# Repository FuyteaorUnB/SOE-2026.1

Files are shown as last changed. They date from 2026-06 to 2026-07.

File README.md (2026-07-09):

# Sistema de Controle de Acesso Biométrico

### Reconhecimento facial e detecção de vivacidade embarcados, com processamento local e núcleo de tempo real







> Portaria eletrônica residencial que reconhece os moradores, detecta ataques de apresentação (foto/tela) e aciona uma trava solenoide, sem enviar nenhum dado biométrico para a nuvem. Todo o processamento acontece dentro de uma Raspberry Pi 3.

**Autor:** Fernando de Melo Colli — 231026349
**Disciplina:** Sistemas Operacionais Embarcados — FCTE / Universidade de Brasília
**Estágio:** Entrega final (migração completa de Python para C/C++)

---

## Índice

- [Visão geral](#visão-geral)
- [Arquitetura de software](#arquitetura-de-software)
- [Hardware](#hardware)
- [Como o reconhecimento funciona](#como-o-reconhecimento-funciona)
- [Viés de dataset descoberto e corrigido](#viés-de-dataset-descoberto-e-corrigido)
- [Detecção de vivacidade (liveness)](#detecção-de-vivacidade-liveness)
- [A decisão final: três barreiras](#a-decisão-final-três-barreiras)
- [Recursos de tempo real do Linux](#recursos-de-tempo-real-do-linux)
- [Como rodar](#como-rodar)
- [Calibração e resultados](#calibração-e-resultados)
- [Estrutura do repositório](#estrutura-do-repositório)
- [Trabalhos futuros](#trabalhos-futuros)
- [Referências](#referências)

---

## Visão geral

Diferente de soluções comerciais como Ring ou Nest, que dependem de servidores externos, este projeto realiza todo o processamento localmente (*Edge Computing*), mantendo o dado biométrico dentro do dispositivo. O sistema é composto por **dois processos concorrentes** que se comunicam por um *pipe* nomeado (FIFO):

| Processo | Papel |
| --- | --- |
| `visao` | Captura a câmera, reconhece o rosto, verifica *liveness* e emite um veredito (`F` = autorizado, `I` = intruso). |
| `sistema_core` | Recebe o veredito e controla o hardware (trava solenoide e LED RGB) com garantias de tempo real. |

**Principais características:**

- Reconhecimento facial **LBPH implementado do zero** — depende apenas do OpenCV base (sem `opencv_contrib`, que leva horas para compilar na Pi).
- Normalização de iluminação **Tan-Triggs** idêntica no treino e na inferência.
- **Múltiplos usuários autorizados** (um rótulo por pessoa) + **classe negativa** para robustez contra intrusos.
- Classe negativa **balanceada por etnia** — corrige um viés de dataset descoberto nos testes.
- **Anti-spoofing** com 4 métricas de vivacidade (LBP, Laplaciano, Sobel, FFT).
- Núcleo de controle com **tempo real**: `mlockall`, `SCHED_FIFO`, afinidade de CPU e tarefa periódica absoluta.
- IPC estável, **sem perda de bytes**, via descritor de leitura persistente com `poll()`.
- Notificação de intruso (foto) via Telegram.

---

## Arquitetura de software

```mermaid
flowchart LR
    CAM([Webcam USB 320x240]) --> VISAO

    subgraph P1 [Processo: visao]
        VISAO[Reconhecimento facial<br/>+ liveness]
    end

    subgraph P2 [Processo: sistema_core]
        CORE[Núcleo de controle<br/>tempo real]
    end

    VISAO -- "FIFO /tmp/gate_pipe<br/>'F' = autorizado<br/>'I' = intruso" --> CORE
    CORE -- GPIO 17 --> TRAVA([Trava solenoide 12V])
    CORE -- GPIO 22/27/10 --> LED([LED RGB])
```

Toda a matemática compartilhada (Tan-Triggs, LBPH, FFT) vive em um único *header*, **`visao_core.hpp`**, o que garante que treino e inferência processem as imagens de forma **idêntica** — a correção central de um bug do estágio anterior.

| Arquivo | Função |
| --- | --- |
| `core.cpp` | Núcleo de controle do hardware + recursos de tempo real |
| `visao.cpp` | Pipeline de visão (reconhecimento + *liveness*) |
| `visao_core.hpp` | Algoritmos compartilhados (Tan-Triggs, LBPH, FFT) |
| `treinar.cpp` | Treino do classificador (captura multi-ângulo e por *datasets*) |
| `extrair_rostos.cpp` | Extração de rostos de terceiros para a classe negativa |
| `baixar_rostos.sh` | Baixa rostos sintéticos (StyleGAN) para a classe negativa |
| `baixar_diversidade.py` | Baixa rostos de etnias sub-representadas (correção do viés) |
| `atualizar_negativos.sh` | Pipeline: baixar → extrair → retreinar, com resumo |
| `Makefile` | Compilação |
| `haarcascade_frontalface_default.xml` | Detector de rostos (Viola-Jones) |

---

## Hardware

### Lista de materiais (BOM)

| Componente | Qtd. |
| --- | ---- |
| Raspberry Pi 3 Model B | 1 |
| Trava Solenoide 12 V | 1 |
| Fonte de Alimentação 12 V | 1 |
| Transistor TIP31C (NPN, potência) | 1 |
| Transistor BC548 (NPN, driver) | 1 |
| Diodo Retificador 1N4007 (*flyback*) | 1 |
| Resistor 330 Ω | 4 |
| Resistor 10 kΩ | 1 |
| LED RGB de cátodo comum | 1 |
| Capacitor Eletrolítico 470 µF / 20 V | 1 |
| Webcam USB | 1 |

### Diagrama de blocos

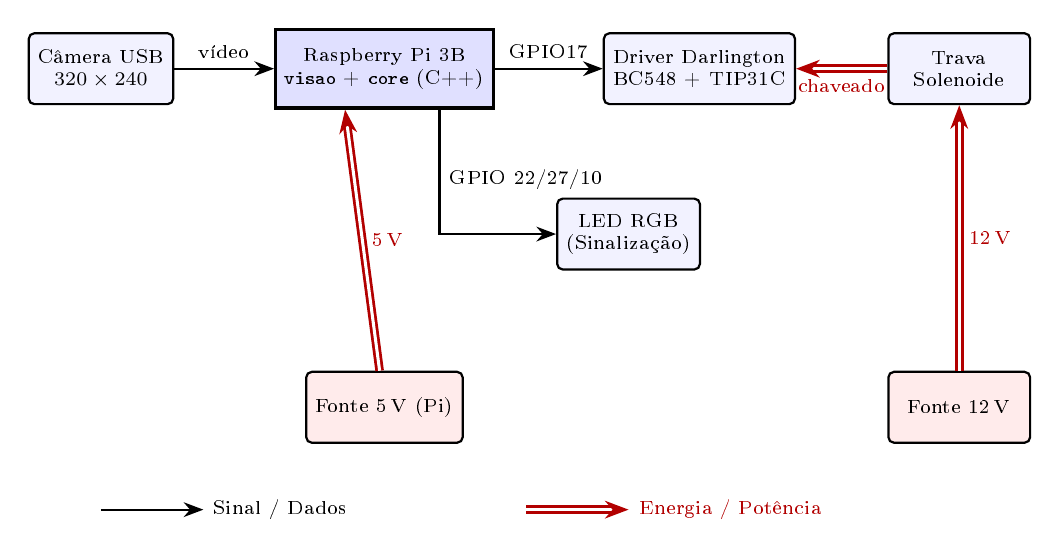
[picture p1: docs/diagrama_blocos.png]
Diagrama de blocos


### Estágio de potência e esquemático

O acionamento da solenoide usa um **par Darlington (BC548 + TIP31C)** como chave de baixo lado:

- **GPIO 17** controla a base do BC548 através de um resistor de **330 Ω**; um resistor de *pull-down* de **10 kΩ** garante o estado desligado sem sinal.
- O coletor do BC548 liga ao **5 V**; o emissor vai à base do TIP31C, cujo coletor chaveia a solenoide.
- A solenoide é alimentada pelo barramento de **12 V**, com um **diodo *flyback* 1N4007** em antiparalelo com a bobina (cátodo no +12 V) para suprimir o pico de tensão reversa no desligamento.
- Um capacitor de **470 µF/20 V** filtra o barramento de 5 V.
- O **LED RGB** (cátodo comum) é acionado pelas **GPIOs 22 / 27 / 10**, cada perna com um resistor de 330 Ω.

> **Terra comum:** as fontes de 5 V (Pi) e 12 V devem compartilhar o **mesmo terra**. A ausência dessa continuidade causa a anomalia do "LED fantasma".

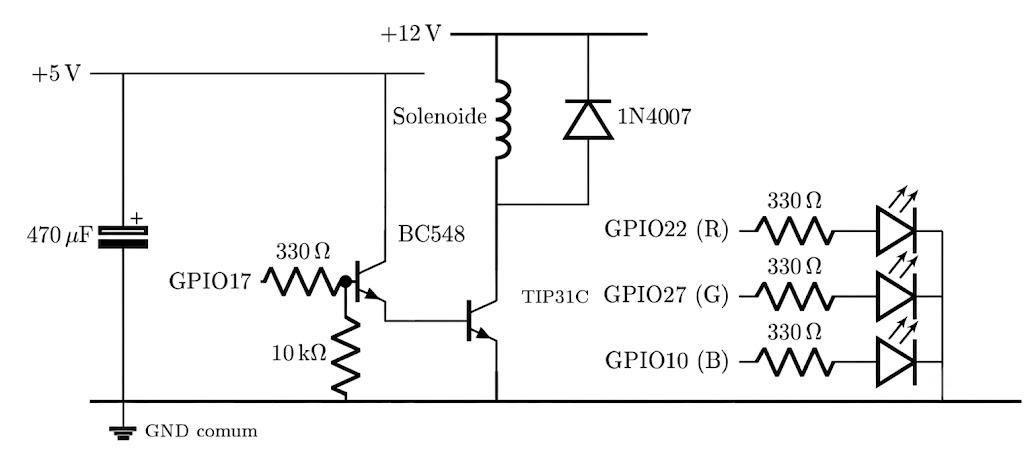
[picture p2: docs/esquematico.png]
Esquemático


---

## Como o reconhecimento funciona

O classificador é um **LBPH (Local Binary Patterns Histograms) por vizinho mais próximo**, implementado do zero. É importante entender que **ele não constrói um retrato médio** — não existe "borrão" de rostos sobrepostos:

1. **Detecção:** o rosto é localizado na cena pelo **Haar Cascade** (Viola-Jones). *(etapa separada e anterior ao reconhecimento)*
2. **Pré-processamento canônico** (`preprocessarFace`): recorte → redimensionamento para **120×120** → normalização **Tan-Triggs** de iluminação. **Aplicado de forma idêntica no treino e na inferência.**
3. **Descrição:** cada rosto vira um **histograma espacial de LBP** — grade **8×8**, 256 *bins* por célula = vetor de **16.384 floats**.
4. **Classificação (1-NN):** o rosto novo é comparado, por **distância χ²**, contra **todas** as amostras guardadas, e recebe o rótulo daquela **mais próxima**.

### Usuários e rótulos

O treino usa **uma pasta por identidade** (lista `USUARIOS_AUTORIZADOS` no `treinar.cpp`):

| Rótulo | Pasta | Conteúdo |
| --- | --- | --- |
| **1**  | `dataset_fernando/` | Usuário autorizado 1 (multi-ângulo) |
| **3**  | `dataset_amigo/` | Usuário autorizado 2 (multi-ângulo) |
| **2**  | `dataset_outros/` | Terceiros — a **classe negativa** |

A captura guiada (`./treinar --capturar`) conduz a pessoa por **7 fases de pose** (frontal, rotações, queixo levantado, perto/longe, contraluz), 30 amostras por fase = **210 amostras por usuário**.

### Por que existe uma "classe negativa"

Cada imagem é guardada como uma **amostra individual** — a classe negativa é uma **galeria de estranhos**, não uma média. O acesso só é liberado quando o rótulo previsto é de um usuário autorizado (≠ 2).

- **Sem a classe negativa:** o `predict()` só teria rótulos autorizados e **sempre** devolveria "usuário". A única defesa seria um limiar de distância — uma fronteira **absoluta** (uma esfera de raio `CONF_MAX` em torno das amostras do usuário). Um rosto parecido (um amigo) pode cair dentro dessa esfera e ser aceito, e apertar o raio passa a rejeitar o próprio usuário.
- **Com a classe negativa:** a decisão passa a ser **relativa** — um rosto só é aceito se estiver **mais próximo de uma amostra de usuário do que de qualquer estranho da galeria**. Mesmo que a distância do intruso até o usuário seja baixa, se houver um estranho ainda mais próximo, o vizinho mais próximo é o rótulo 2 → **acesso negado**, independentemente do limiar.

> Em uma frase: troca-se uma fronteira esférica frágil ("está perto de mim?") por uma fronteira de Voronoi discriminativa ("parece mais comigo ou com algum estranho?").

---

## Viés de dataset descoberto e corrigido

Durante os testes com voluntários, o sistema **barrava estranhos brancos mas aceitava um voluntário asiático** como usuário autorizado. A causa: a classe negativa vinha de terceiros locais e da StyleGAN do *thispersondoesnotexist* (treinada no dataset FFHQ), **ambos enviesados para rostos brancos**. Sem nenhum negativo asiático próximo no espaço de características, o rosto do voluntário caía no vizinho autorizado mais parecido — um falso positivo **estrutural**.

**Correção:** o script `baixar_diversidade.py` baixa rostos de nove grupos étnicos sub-representados; `extrair_rostos` os recorta e `treinar` reconstrói o modelo. Após o balanceamento, o falso positivo desapareceu.

> É um caso concreto de **viés de dataset em *open-set recognition***: a robustez da fronteira discriminativa depende diretamente da cobertura da galeria negativa.

---

## Detecção de vivacidade (liveness)

Para cada quadro, quatro métricas atacam ataques de apresentação (foto impressa ou tela de celular):

| Métrica | O que mede | Limiar |
| --- | --- | --- |
| **LBP** (variância de padrões uniformes) | Textura de pele real vs. superfície plana | `> 3.7`  |
| **Laplaciano** (variância) | Nitidez / micro-detalhe | `> 28` |
| **Sobel** (desvio do gradiente) | Riqueza de bordas | `> 12` |
| **FFT** (razão de energia alta/baixa freq.) | Detalhe de alta frequência ausente em telas | `> 0.65` |

Um quadro é considerado **REAL** se o *score* ≥ 3 **e** LBP **e** FFT passarem.

---

## A decisão final: três barreiras

Os vereditos por quadro entram em **janelas deslizantes de 10 quadros** (com *reset* após 12 s sem rosto). A porta só abre quando **as três barreiras** são satisfeitas ao mesmo tempo:

1. **Identidade consistente:** ≥ **9/10** quadros da **mesma** identidade autorizada (rótulo ≠ 2, `Conf < 38`);
2. **Vivacidade:** ≥ **6/10** quadros REAIS, com **pico de Laplaciano > 80** na janela (ao menos um quadro nítido);
3. **Distância:** abaixo de `CONF_MAX` em cada quadro contado.

Satisfeitas as três → `F` no FIFO (trava abre por 4 s). Se menos de 4 quadros forem reais ou autorizados → `I` + **foto da cena no Telegram** (intervalo mínimo de 20 s entre notificações). Um intruso não consegue satisfazer as três barreiras simultaneamente.

---

## Recursos de tempo real do Linux

O `sistema_core` emprega recursos de tempo real para garantir **latência determinística** no acionamento da trava:

| Recurso | Chamada de sistema | Efeito |
| --- | --- | --- |
| **Memória travada** | `mlockall(MCL_CURRENT \| MCL_FUTURE)` | Impede que páginas vão para o *swap* em um momento crítico |
| **Escalonamento RT** | `SCHED_FIFO` (prioridade 50) | A thread crítica executa assim que o byte chega, sem ser preemptada |
| **Afinidade de CPU** | `pthread_setaffinity_np` | Monitor na CPU 3, LED na CPU 2 — evita migração e *jitter* de cache |
| **Tarefa periódica absoluta** | `clock_nanosleep(CLOCK_MONOTONIC, TIMER_ABSTIME)` | LED em período exato de 100 ms, sem *drift* acumulado |

O núcleo usa duas threads (`std::thread`): uma que escuta o FIFO com `poll()` (sem *busy-wait*) e outra que atualiza o LED. O estado compartilhado é protegido por `std::mutex`, e `SIGINT`/`SIGTERM` garantem encerramento limpo.

> Os recursos de tempo real exigem privilégios — rode o `sistema_core` com `sudo`.

---

## Como rodar

> **Ambiente-alvo:** Raspberry Pi 3 Model B (ou qualquer Linux com OpenCV base e V4L2).

### 1. Dependências

```bash
sudo apt update
sudo apt install -y g++ make libopencv-dev pkg-config
# 'pinctrl' já vem no Raspberry Pi OS recente (usado para as GPIOs)
```

### 2. Compilar

```bash
make            # gera: sistema_core, visao e treinar
```

Para (re)gerar a ferramenta da classe negativa (não incluída no `make all`):

```bash
g++ -O2 -std=c++17 $(pkg-config --cflags opencv4) \
    extrair_rostos.cpp -o extrair_rostos $(pkg-config --libs opencv4)
```

### 3. Treinar o classificador

**a) Capturar os rostos dos usuários autorizados** (guia interativo de 7 ângulos):

```bash
./treinar --capturar                        # usuário 1 → dataset_fernando/ (rótulo 1)
./treinar --capturar dataset_amigo 3        # usuário 2 → dataset_amigo/  (rótulo 3)
```

**b) Montar a classe negativa** — automática (recomendado):

```bash
./atualizar_negativos.sh 60      # baixa 60 rostos sintéticos, extrai e retreina
python3 baixar_diversidade.py    # rostos de etnias diversas (balanceamento)
./extrair_rostos fotos_diversas/*/*.jpg
```

ou manual, com fotos próprias:

```bash
./extrair_rostos foto1.jpg foto2.jpg ...
```

**c) Treinar a partir das pastas** (gera `modelo_lbph.txt`):

```bash
./treinar
```

### 4. Calibrar (opcional, recomendado)

Roda o pipeline **sem disparar ações**, só imprimindo métricas — útil para ajustar os limiares:

```bash
./visao --calibrar
```

### 5. Executar o sistema

Em **dois terminais** (ou via `systemd` / `&`):

```bash
# Terminal 1 — núcleo de controle (precisa de sudo p/ tempo real e GPIO)
sudo ./sistema_core
```

```bash
# Terminal 2 — pipeline de visão
./visao
```

Para as notificações do Telegram, defina `TELEGRAM_TOKEN` e `TELEGRAM_CHAT_ID` no topo do `visao.cpp` antes de compilar (**não versione o token** — o valor padrão `COLOQUE_SEU_...` mantém as notificações desativadas).

> Os binários carregam `haarcascade_frontalface_default.xml`, `modelo_lbph.txt` e as pastas `dataset_*` **pelo diretório de trabalho atual** — rode-os a partir da pasta onde esses arquivos estão. `make clean` remove os binários.

---

## Calibração e resultados

A calibração foi **iterativa, com pessoas reais** (modo `--calibrar`). Os limiares finais:

| Parâmetro | Valor |
| --- | ----- |
| `CONF_MAX` (distância χ² máxima) | 38 |
| `LBP_MIN` | 3,7 |
| `LAP_MIN` | 28 |
| `GRAD_STD_MIN` | 12 |
| `FFT_RATIO` | 0,65  |
| `LAP_PICO_MIN` (pico na janela)  | 80 |

**Composição final do modelo (`modelo_lbph.txt`): 833 amostras** — 210 do usuário 1, 210 do usuário 2 e 413 negativos balanceados por etnia.

**Resultados:**

- **Identidade:** usuários legítimos aceitos de forma consistente, com `Conf` **34–38 estável** sob variação de iluminação (era **84–98** antes da correção Tan-Triggs).
- **Intruso:** classificado como rótulo 2 em **80–90%** dos quadros → a barreira de identidade (≥ 9/10) impede a abertura.
- **Viés corrigido:** após o balanceamento étnico da classe negativa, o falso positivo estrutural desapareceu.
- **Anti-spoofing:** foto em tela de celular → rótulo 2 ou reprovação nas métricas de textura → alerta + notificação no Telegram.
- **IPC:** estável, **sem perda de bytes**, graças ao descritor de leitura persistente com `poll()`.
- **Tempo real:** `mlockall`, `SCHED_FIFO` e afinidade de CPU bem-sucedidos nos quatro núcleos da Pi 3; LED em período exato de 100 ms.
- **CPU:** consumo baixo, pela ausência de *busy-wait* e pelo *sleep* de 150 ms entre quadros.

---

## Estrutura do repositório

```
.
├── README.md
├── Makefile
├── .gitignore
├── core.cpp                              # Núcleo de controle + tempo real
├── visao.cpp                             # Pipeline de visão (liveness + reconhecimento)
├── visao_core.hpp                        # Algoritmos compartilhados (Tan-Triggs, LBPH, FFT)
├── treinar.cpp                           # Treino do classificador
├── extrair_rostos.cpp                    # Extração de rostos p/ a classe negativa
├── baixar_rostos.sh                      # Rostos sintéticos (negativos genéricos)
├── baixar_diversidade.py                 # Rostos de etnias diversas (balanceamento)
├── atualizar_negativos.sh                # Pipeline: baixar → extrair → retreinar
├── haarcascade_frontalface_default.xml   # Detector de rostos
└── docs/
    ├── Trabalho_SOE.pdf                  # Relatório final do projeto
    ├── diagrama_blocos.png
    ├── esquematico.png
    ├── fluxograma.png
    └── SOE-v1.fzz                        # Projeto Fritzing do circuito
```

> **Observação:** o modelo `modelo_lbph.txt` e as pastas `dataset_*/` e `fotos_*/` são **dados biométricos**, gerados localmente e **não versionados** (ver `.gitignore`). As credenciais do bot do Telegram também não são versionadas.

---

## Trabalhos futuros

- Substituir o LBPH por **embeddings faciais de rede neural** (mais tolerantes a pose e iluminação).
- Migrar o acionamento de GPIO de `system("pinctrl")` para **libgpiod** (menos *overhead* e mais determinismo na thread de tempo real).

---

## Referências

- P. Viola, M. Jones — *Rapid Object Detection using a Boosted Cascade of Simple Features*, CVPR 2001.
- T. Ojala, M. Pietikäinen, T. Mäenpää — *Multiresolution Gray-Scale and Rotation Invariant Texture Classification with LBP*, IEEE PAMI 2002.
- T. Ahonen, A. Hadid, M. Pietikäinen — *Face Description with Local Binary Patterns*, IEEE PAMI 2006.
- X. Tan, B. Triggs — *Enhanced Local Texture Feature Sets for Face Recognition under Difficult Lighting Conditions*, IEEE TIP 2010.
- T. Karras, S. Laine, T. Aila — *A Style-Based Generator Architecture for Generative Adversarial Networks*, CVPR 2019.
- W. R. Stevens, S. A. Rago — *Advanced Programming in the UNIX Environment*, 3rd ed., 2013.
- M. Kerrisk — *The Linux Programming Interface*, No Starch Press, 2010.

---

*Desenvolvido para a disciplina de Sistemas Operacionais Embarcados — FCTE / UnB · 2026*

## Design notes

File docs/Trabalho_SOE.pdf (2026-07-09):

# Sistema de Controle de Acesso Biométrico com Processamento Local e Defesa contra Ataques de Apresentação

Fernando de Melo Colli - 231026349 Faculdade de Ciências e Tecnologias em Engenharia (FCTE) Universidade de Brasília

Resumo—Este trabalho apresenta a entrega final de um sistema de controle de acesso residencial biométrico, embarcado integralmente em uma Raspberry Pi 3 Model B com processamento local (Edge Computing) — o dado biométrico não sai do dispositivo. O software, todo em C/C++, consolida um sistema concorrente de dois processos que se comunicam por um pipe nomeado (FIFO): uma pipeline de visão (visao) e um núcleo de controle de tempo real (sistema_core), que emprega travamento de memória (mlockall), escalonamento SCHED_FIFO, afinidade de CPU e tarefa periódica com clock_nanosleep absoluto, garantindo latência determinística no acionamento da trava. O reconhecimento facial (LBPH implementado do zero, sem dependência do opencv_contrib) usa normalização de iluminação Tan-Triggs idêntica no treino e na inferência, suporta múltiplos usuários autorizados e emprega uma classe negativa — uma galeria de rostos de terceiros — que transforma o limiar absoluto de distância em uma fronteira discriminativa contra intrusos. Durante os testes, identificou-se e corrigiu-se um viés étnico nessa classe negativa, um caso concreto de viés de dataset em reconhecimento de conjunto aberto (open-set). A decisão de abertura exige três barreiras simultâneas em uma janela deslizante de 10 quadros: identidade consistente, vivacidade (liveness, 4 métricas anti-spoofing) e distância abaixo do limiar. Os resultados demonstram um protótipo estável: identidade consistente sob variação de iluminação, rejeição de intrusos e de ataques de apresentação, e comunicação entre processos sem perda de bytes.

I. INTRODUÇÃO

A segurança residencial demanda autonomia e privacidade. Diferente de soluções comerciais como Ring [1] ou Nest [2], que dependem de servidores externos, este projeto realiza todo o processamento localmente (Edge Computing), mantendo o dado biométrico dentro do dispositivo. O sistema implementa uma portaria eletrônica com reconhecimento facial, detecção de vivacidade (liveness) e acionamento de uma trava solenoide. Esta entrega final consolida o refinamento do protótipo ao longo dos pontos de controle, com cinco objetivos: (i) migrar todo o código de Python para C/C++; (ii) adicionar recursos de tempo real do Linux ao núcleo de controle [9], [10]; (iii) corrigir os falsos negativos de identidade observados no PC3 sob variação de iluminação; (iv) tornar o classificador robusto contra intrusos por meio de uma classe negativa, com suporte a múltiplos usuários autorizados; e (v) identificar e corrigir o viés étnico descoberto nessa classe negativa durante os testes com pessoas reais. As seções seguintes descrevem o hardware

(II-A), a arquitetura de software em C++ (II-B), o processo de calibração e os resultados (III).

II. DESENVOLVIMENTO DO PROJETO

A. Descrição de Hardware

O sistema utiliza uma Raspberry Pi 3 Model B como núcleo. A lógica de controle e a sinalização (driver e LED RGB) são alimentadas pelo barramento de 5 V da própria Pi, enquanto a trava solenoide é acionada por uma fonte de 12 V. As duas fontes compartilham um barramento de terra comum — ponto cuja garantia corrige a anomalia elétrica (LED fantasma) observada no PC3. A Tabela I lista os materiais.

Tabela I
LISTA DE MATERIAIS (BOM) – IMPLEMENTAÇÃO REAL (PC4)
Componente | Quantidade
Raspberry Pi 3 Model B | 1
Trava Solenoide 12 V | 1
Fonte de Alimentação 12 V | 1
Transistor TIP31C (NPN, potência) | 1
Transistor BC548 (NPN, driver) | 1
Diodo Retificador 1N4007 (flyback) | 1
Resistor 330 Ω | 4
Resistor 10 kΩ | 1
LED RGB de cátodo comum | 1
Capacitor Eletrolítico 470 µF / 20 V | 1
Webcam USB | 1
1) Diagrama de Blocos: O diagrama de blocos da Fig. 1 mostra os componentes de hardware. Os fluxos de sinal/dados aparecem como setas finas e os de energia/potência como setas grossas duplas. A lógica é alimentada pelo barramento de 5 V da Raspberry Pi e a solenoide por uma fonte de 12 V, ambas com terra comum.


Figura 1. Diagrama de blocos do sistema: componentes de hardware, com distinção entre fluxos de sinal (setas finas) e de energia (setas grossas).

2) Estágio de Potência e Esquemático: O acionamento da solenoide usa um par Darlington (BC548 + TIP31C) como chave de baixo lado. A GPIO 17 controla a base do BC548 através de um resistor de 330 Ω; um resistor de pull-down de 10 kΩ garante o estado desligado na ausência de sinal. O coletor do BC548 liga-se ao 5 V e seu emissor à base do TIP31C, cujo coletor chaveia a solenoide e cujo emissor vai ao terra. A solenoide é alimentada pelo barramento de 12 V (terminal positivo no +12 V), e um diodo flyback 1N4007 fica em antiparalelo com a bobina (cátodo, lado da listra cinza, no +12 V) para suprimir o pico de tensão reversa no desligamento. Um capacitor eletrolítico de 470 µF/20 V filtra o barramento de 5 V. O LED RGB de cátodo comum é acionado pelas GPIOs 22/27/10, cada perna com um resistor de 330 Ω. O esquemático completo é apresentado na Fig. 2.

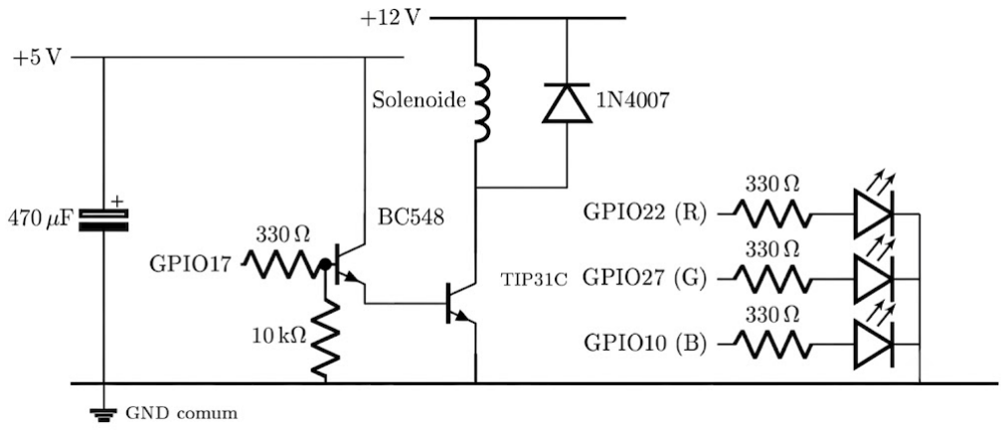
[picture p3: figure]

Figura 2. Esquema elétrico: par Darlington BC548 + TIP31C acionando a solenoide a partir do barramento de 12 V, com diodo de roda-livre 1N4007, capacitor de filtro de 470 µF e LED RGB de sinalização.

B. Descrição de Software

Todos os scripts Python dos estágios anteriores foram reescritos em C++. O sistema permanece como dois processos independentes sincronizados por um pipe nomeado (FIFO) em /tmp/gate_pipe: o processo visao envia o veredito (’F’ = autorizado, ’I’ = intruso) e o sistema_core aciona o hardware. A Tabela II resume a migração.

Tabela II
MIGRAÇÃO DE PYTHON (PC3) PARA C++ (ENTREGA FINAL).
PC3 (Python) | Final (C++) | Função
vision.py | visao.cpp | Pipeline de visão
treinar_e_ver.py | treinar.cpp | Treino do classificador
treinar_increm.py | (no treinar.cpp) | Absorvido
main.cpp | core.cpp | Núcleo + tempo real
— | visao_core.hpp | Algoritmos compartilhados
— | extrair_rostos.cpp | Extração de rostos
1) Núcleo de Controle e Recursos de Tempo Real: O core.cpp controla exclusivamente o hardware por meio
de duas threads (std::thread): threadMonitorPipe,
que escuta o FIFO com poll() (sem busy-wait), e threadControleLED, que atualiza a sinalização. O estado compartilhado é protegido por std::mutex (mtx para o estado e hwMtx para serializar o acesso às GPIOs), e os sinais SIGINT/SIGTERM garantem encerramento limpo. Sobre essa base, empregam-se quatro recursos de tempo real do Linux:
- [RT1] mlockall(MCL_CURRENT | MCL_FUTURE)
— trava toda a memória do processo na RAM, impedindo que páginas sejam enviadas ao swap em um momento crítico (Listagem 1).
- [RT2] SCHED_FIFO — a thread crítica recebe escalonamento de tempo real com prioridade fixa (50), executando imediatamente quando o byte chega, sem ser preemptada por processos comuns.
- [RT3] Afinidade de CPU — cada thread é fixada em um núcleo (monitor na CPU 3, LED na CPU 2), evitando migração entre núcleos e o jitter associado à invalidação de cache (Listagem 2).
- [RT4] Tarefa periódica absoluta — a thread do LED
usa clock_nanosleep com CLOCK_MONOTONIC e
TIMER_ABSTIME: o próximo instante é sempre “anterior + 100 ms”, sem o drift acumulado do sleep_for comum (Listagem 3).
if (mlockall(MCL_CURRENT | MCL_FUTURE) == 0)
std::cout << "[RT] Memoria travada na RAM.\n";

Listing 1. Travamento de memória na RAM (core.cpp).

bool configurarTempoReal(int prioridade, int cpu, const char* nome) {
cpu_set_t set; CPU_ZERO(&set); CPU_SET(cpu, &set); pthread_setaffinity_np(pthread_self(), sizeof(set), & set); // [RT3]
struct sched_param sp; std::memset(&sp, 0, sizeof(sp)); sp.sched_priority = prioridade;
// [RT2]
return pthread_setschedparam(pthread_self(), SCHED_FIFO , &sp) == 0;
}

Listing 2. SCHED_FIFO e afinidade de CPU (core.cpp).

const long PERIODO_NS = 100L*1000L*1000L; // 100 ms struct timespec proximo; clock_gettime(CLOCK_MONOTONIC, & proximo);
while (rodando) {
/* ... atualiza LED conforme estado ... */ proximo.tv_nsec += PERIODO_NS;
while (proximo.tv_nsec >= 1000000000L) { proximo. tv_nsec -= 1000000000L; proximo.tv_sec++; }

clock_nanosleep(CLOCK_MONOTONIC, TIMER_ABSTIME, & proximo, nullptr);
}

Listing 3. Período exato com clock_nanosleep absoluto (core.cpp).

Tabela III
RECURSOS DE SISTEMA OPERACIONAL EMPREGADOS.
Recurso | Chamada de sistema
Múltiplos processos | visao + sistema_core
Threads | std::thread
Pipe nomeado (IPC) | mkfifo/open/read/write
Sinais | signal(SIGINT/SIGTERM)
Exclusão mútua | std::mutex (mtx, hwMtx)
E/S eficiente | poll() com timeout
Memória travada [RT1] | mlockall()
Escalonamento RT [RT2] | SCHED_FIFO
Afinidade de CPU [RT3] | pthread_setaffinity_np()
Tarefa periódica [RT4] | clock_nanosleep(ABSTIME)
2) Algoritmos Compartilhados (visao_core.hpp): | Todo
o “coração matemático” do sistema fica no header visao_core.hpp, garantindo que treino e inferência processem as imagens de forma idêntica. Como o módulo cv::face pertence ao opencv_contrib (que não vem no pacote padrão da Pi e leva horas para compilar), o classificador LBPH foi reimplementado do zero [6], [7], dependendo apenas do OpenCV base [3]. O header reúne: tanTriggs() (normalização de iluminação), preprocessarFace() (recorte, redimensionamento para 120 × 120 e Tan-Triggs),
computeLBP(), spatialHistogram() (grade 8 × 8,
256 bins por célula, vetor de 16.384 floats), chiSquare() (distância χ

2
), a struct LBPHModel (treino, predict
por vizinho mais próximo, persistência em texto) e as métricas
de liveness fftRatio() e lbpUniformVar().
3) Correção dos Falsos Negativos: Normalização Tan-Triggs: No PC3, o LBPH retornava distâncias de 84 a 98 para o usuário legítimo sob iluminação diferente da do treino, rejeitando-o. A causa raiz era um pipeline assimétrico: o treino usava a ROI bruta, enquanto a inferência aplicava CLAHE apenas na detecção — o modelo aprendia uma textura e tentava reconhecer outra. A correção foi a normalização Tan-Triggs [8], aplicada de forma idêntica nos dois lados via preprocessarFace() (Listagem 4). Ela combina correção gamma, diferença de Gaussianas (remove a iluminação de baixa frequência) e equalização de contraste com saturação em tanh. Resultado: o mesmo rosto sob luz forte ou fraca gera imagens processadas semelhantes, e a distância do usuário legítimo caiu para a faixa 34–38, estável.

inline cv::Mat preprocessarFace(const cv::Mat& grayFrame, const cv::Rect& r) {
cv::Rect rr = r & cv::Rect(0,0,grayFrame.cols,grayFrame .rows);
if (rr.width < 40 || rr.height < 40) return cv::Mat(); cv::Mat roi = grayFrame(rr), resized;
cv::resize(roi, resized, cv::Size(FACE_SIZE, FACE_SIZE) , 0,0, cv::INTER_AREA);
return tanTriggs(resized); // mesma normalizacao dos dois lados
}

Listing 4. Pré-processamento canônico, idêntico no treino e na inferência (visao_core.hpp).

4) Múltiplos Usuários e Classe Negativa: O treino (treinar.cpp) lê uma pasta por identidade (Tabela IV). No modo -capturar, um guia interativo conduz o usuário por 7 fases de pose (frontal, rotações, queixo levantado, distâncias e contraluz), coletando 30 amostras por fase — 210 por usuário — o que dá ao modelo tolerância a ângulo e enquadramento. Cada imagem é armazenada como uma amostra individual no modelo: a classe negativa não é um “retrato médio” de estranhos, e sim uma galeria de rostos de terceiros com rótulo 2, montada com a ferramenta extrair_rostos.cpp (detecta os rostos das imagens de entrada, recorta-os para 120 × 120 e acumula em dataset_outros/ sem sobrescrever).

Tabela IV
IDENTIDADES E RÓTULOS DO CLASSIFICADOR.
Pasta | Identidade | Rótulo
dataset_fernando/ | Usuário 1 (autorizado) | 1
dataset_amigo/ | Usuário 2 (autorizado) | 3
dataset_outros/ | Terceiros (classe negativa) | 2

Sem a classe negativa, o predict() só conheceria rótulos autorizados e sempre responderia “é um usuário”; a única defesa seria o limiar de distância — uma fronteira absoluta e frágil, pois um rosto parecido pode cair dentro dela. Com a galeria de estranhos, a decisão torna-se relativa: um rosto só é aceito se estiver mais próximo de uma amostra de usuário autorizado do que de qualquer estranho da galeria (vizinho mais próximo por distância χ

| 2
). Um quadro só
conta como autorizado quando o rótulo previsto é de usuário (diferente de 2) e a distância fica abaixo de CONF_MAX; o intruso classificado como rótulo 2 é barrado automaticamente, independentemente da distância. Em uma frase: troca-se uma fronteira esférica (“está perto de mim?”) por uma fronteira discriminativa (“parece mais comigo ou com algum estranho?”).
5) Ferramentas de Montagem da Classe Negativa: Três scripts auxiliares (fora do sistema em tempo de execução) automatizam a construção e manutenção dos negativos: baixar_rostos.sh baixa rostos sintéticos do serviço thispersondoesnotexist (gerados por StyleGAN [11]), validando o formato JPEG e descartando duplicatas por hash MD5; baixar_diversidade.py baixa, via mecanismos de busca de imagens, rostos de etnias sub-representadas, usado na correção do viés descrito na Seção III-B; e
atualizar_negativos.sh encadeia download, extração
(extrair_rostos) e retreino em um único comando, imprimindo um resumo do modelo resultante.
6) Pipeline de Visão (visao.cpp): Para cada quadro 320 × 240: conversão para cinza, CLAHE [5] (apenas na detecção), detecção por Haar Cascades [4], preprocessarFace(), predict() (rótulo + distância) e quatro métricas de liveness (variância de LBP uniforme, variância do Laplaciano, desvio do gradiente de Sobel e razão de energia na FFT). Um quadro é REAL se o score ≥ 3 das 4 métricas passar, sendo LBP e FFT obrigatórias. Os vereditos entram em janelas deslizantes (deque de 10 quadros, com reset após 12 s sem rosto), e a porta só abre quando três barreiras são satisfeitas simultaneamente na janela:
1) Identidade consistente: ≥ 9/10 quadros da mesma identidade autorizada (rótulo ̸= 2, distância <
CONF_MAX);
2) Vivacidade: ≥ 6/10 quadros REAIS, com pico de variância do Laplaciano > 80 na janela (exige ao menos um quadro nítido, contra desfoque proposital);
3) Distância: abaixo do limiar CONF_MAX em cada quadro contado.
Satisfeitas as três, envia-se ’F’ pelo FIFO; se menos de 4 quadros forem reais ou autorizados, envia-se ’I’ e uma foto da cena é enviada ao Telegram (com intervalo mínimo de 20 s entre notificações). O modo -calibrar executa o mesmo pipeline sem disparar ações, apenas imprimindo o placar de métricas — foi o instrumento de ajuste de todos os limiares. O fluxograma é apresentado na Fig. 3.

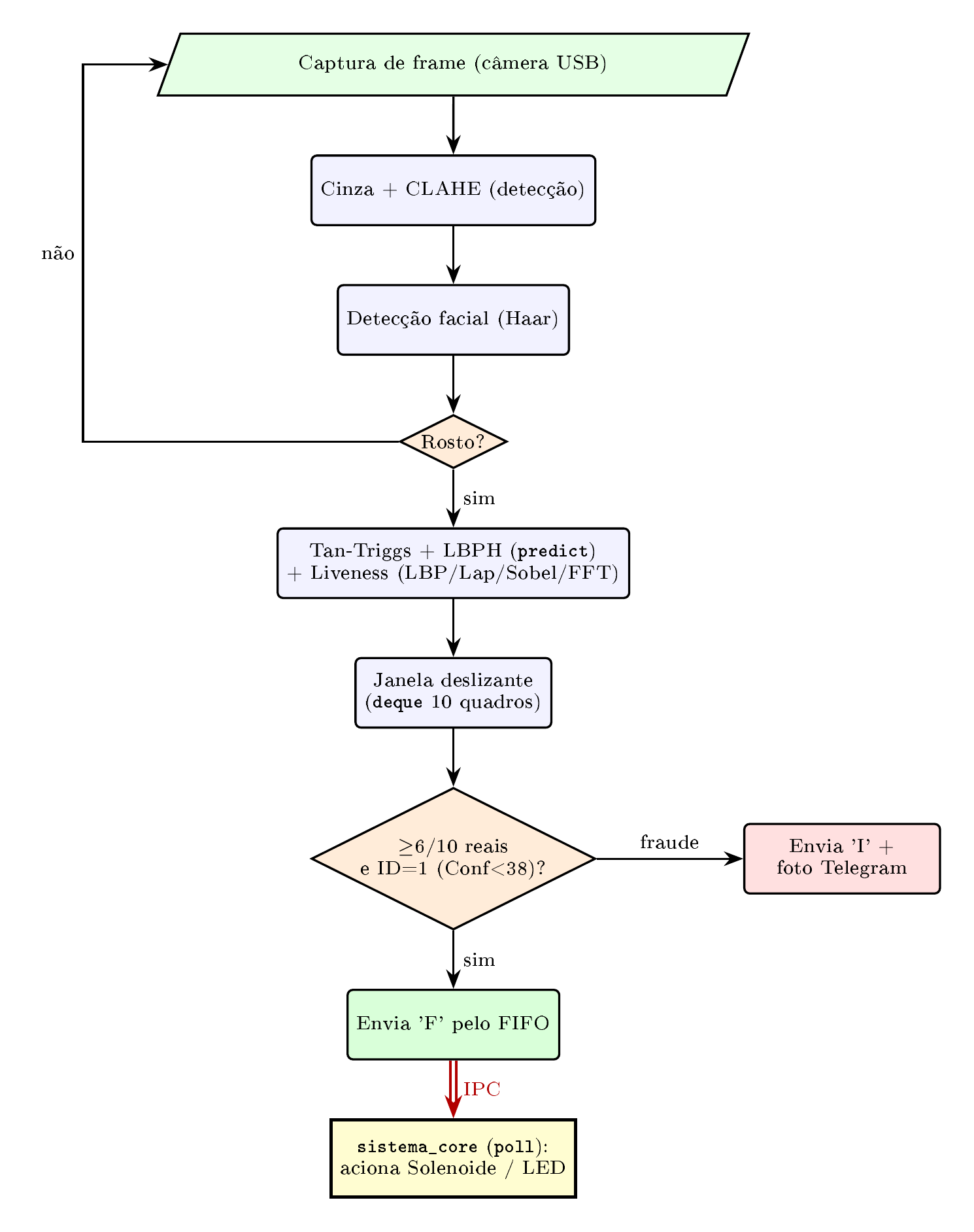
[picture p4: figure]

Figura 3. Fluxograma do pipeline de visão: da captura ao acionamento do hardware via IPC.

III. CALIBRAÇÃO E RESULTADOS EXPERIMENTAIS

A. Processo de Calibração

A calibração foi iterativa, com pessoas reais, usando o modo -calibrar. Inicialmente, com CONF_MAX=55, um terceiro não autorizado conseguia abrir o sistema (distâncias entre 36 e 48, sobrepondo-se às do usuário). A primeira iteração reduziu o limiar para CONF_MAX=38, o que melhorou mas não resolveu (o terceiro ainda descia a 35–37 em certas posições). A segunda iteração adicionou a classe negativa, após a qual ele passou a ser classificado como rótulo 2 na maioria dos quadros, sendo barrado pelo critério de identidade. Os limiares finais são: CONF_MAX=38, LBP_MIN=3,7, LAP_MIN=28,
GRAD_STD_MIN=12 e FFT_RATIO=0,65.
B. Viés de Dataset na Classe Negativa

Durante os testes com voluntários, observou-se um comportamento assimétrico: o sistema barrava corretamente estranhos brancos, mas aceitava um voluntário asiático como usuário autorizado. A investigação revelou a causa: a classe negativa era composta por terceiros locais e por rostos sintéticos da StyleGAN [11] (treinada no dataset FFHQ), ambos enviesados para rostos brancos. Sem nenhum negativo asiático por perto no espaço de características, o rosto do voluntário caía no vizinho autorizado mais parecido — um falso positivo estrutural, não um caso isolado. A correção foi balancear a classe negativa por etnia com o script baixar_diversidade.py (nove grupos de busca, cobrindo etnias sub-representadas), seguido de extração e retreino via atualizar_negativos.sh. Após o balanceamento, o falso positivo desapareceu: o voluntário passou a ser classificado como rótulo 2. Trata-se de um caso concreto de viés de dataset em reconhecimento de conjunto aberto (open-set recognition): a robustez da fronteira discriminativa depende diretamente da cobertura da galeria negativa.

C. Composição Final do Modelo
A | Tabela | V | apresenta | a | composição | do
modelo_lbph.txt | final, com a classe negativa já
balanceada.

Tabela V
COMPOSIÇÃO FINAL DO MODELO (833 AMOSTRAS).
Pasta | Rótulo | Amostras
dataset_fernando/ | 1 (autorizado) | 210
dataset_amigo/ | 3 (autorizado) | 210
dataset_outros/ | 2 (negativa) | 413
Total | | 833
D. Resultados

A Listagem 5 mostra um log típico do usuário legítimo, e a Fig. 4 o protótipo montado.

ID=1(Conf:35.4) | LBP=4.3O LAP=121.4O GRD=18.7O FFT=0.83O
[4/4] -> [REAL]
ID=1(Conf:36.8) | LBP=4.2O LAP=110.7O GRD=17.9O FFT=0.79O
[4/4] -> [REAL]
[ACESSO CONCEDIDO] Identidade e liveness confirmados. [CORE] Acesso autorizado. Abrindo trava.

Listing 5. Log de execução: reconhecimento e liveness do usuário legítimo.

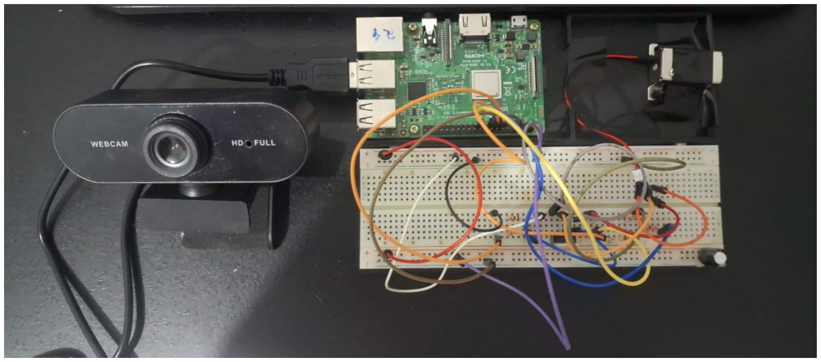
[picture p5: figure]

Figura 4. Protótipo montado: Raspberry Pi 3, estágio de potência em protoboard, trava solenoide, LED RGB e webcam USB.

Os principais resultados são:

- Identidade: usuários legítimos aceitos de forma consistente, com Conf 34–38 estável sob variação de iluminação (era 84–98 no PC3);
- Intruso: com a classe negativa balanceada, classificado como rótulo 2 em 80–90% dos quadros; a barreira de identidade (≥ 9/10 da mesma identidade autorizada) impede a abertura;
- Anti-spoofing: foto impressa ou em tela de celular resulta em rótulo 2 ou em reprovação nas métricas de textura/-frequência (superfícies planas) ⇒ alerta de intruso, com notificação e foto no Telegram (Fig. 5);
- IPC: estável, sem perda de bytes, graças ao descritor de leitura persistente com poll();
- Tempo real: mlockall, SCHED_FIFO e afinidade de CPU bem-sucedidos (com sudo) nos quatro núcleos da Pi 3; o LED opera em período exato de 100 ms;
- CPU: consumo baixo, pela ausência de busy-wait (poll()) e pelo sleep de 150 ms entre quadros na visão.

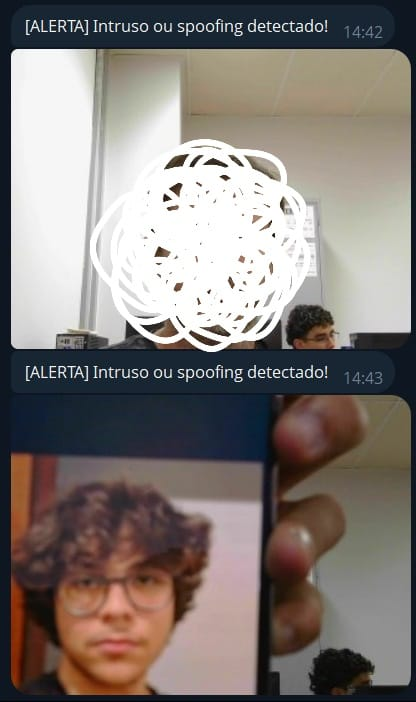
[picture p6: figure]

Figura 5. Notificação de intruso recebida no Telegram: mensagem de alerta seguida da foto da cena capturada pelo sistema.

E. Evoluções em Relação aos Estágios Anteriores

Cinco problemas foram corrigidos ao longo do refinamento:
(i) perda de bytes no IPC — o lado leitor abria/fechava o FIFO a cada verificação, criando janelas sem leitor; resolvido mantendo o descritor de leitura persistente com poll(); (ii) pipeline assimétrico entre treino e inferência, resolvido por preprocessarFace() (Seção II-B); (iii) CLAHE recriado a cada quadro, agora instanciado uma única vez fora do laço; (iv) a anomalia elétrica do LED fantasma, causada pelo rompimento do barramento de terra comum entre as fontes de 5 V e 12 V, eliminada com a troca dos jumpers e a garantia da continuidade desse terra; e (v) o viés étnico da classe negativa (Seção III-B), corrigido pelo balanceamento dos negativos.

IV. CONCLUSÕES

A entrega final consolidou o protótipo em um sistema integrado, inteiramente em C/C++, estável e sem as falhas dos estágios anteriores. A migração permitiu acoplar recursos de tempo real do Linux (memória travada, escalonamento SCHED_FIFO, afinidade de CPU e tarefa periódica absoluta) que garantem latência determinística no acionamento da trava. As correções biométricas centrais — a normalização Tan-Triggs idêntica entre treino e inferência, a classe negativa como galeria de estranhos e o suporte a múltiplos usuários autorizados — resolveram, respectivamente, os falsos negativos de identidade e a fragilidade do classificador de classe única, enquanto a decisão em três barreiras (identidade ≥ 9/10, vivacidade ≥ 6/10 e distância sob o limiar) tornou a abertura robusta contra intrusos e ataques de apresentação.
Três aprendizados se destacam. Primeiro, a robustez de um sistema embarcado depende tanto do software quanto da integridade física: a anomalia de terra do PC3 reforçou a atenção à continuidade do barramento de terra comum entre as fontes de 5 V e 12 V. Segundo, a coerência do pipeline de pré-processamento entre treino e inferência é tão importante quanto a escolha do classificador. Terceiro — e talvez o mais relevante —, a qualidade de um classificador de conjunto aberto é limitada pela cobertura da sua classe negativa: o viés étnico descoberto nos testes mostrou, na prática, como um dataset enviesado produz falhas de segurança silenciosas e sistemáticas, e como o balanceamento da galeria as elimina. Como trabalhos futuros, propõe-se a substituição do LBPH por embeddings faciais de rede neural (mais tolerantes a pose e iluminação), a migração do acionamento de GPIO de
system("pinctrl") para a biblioteca libgpiod (menor
overhead na thread de tempo real) e a implementação da senha temporária para entregadores prevista desde o PC1.

AGRADECIMENTOS

O autor agradece ao professor e aos colegas da disciplina de Sistemas Operacionais Embarcados pelas sugestões ao longo dos pontos de controle, que orientaram o refinamento do protótipo.

REFERÊNCIAS

[1] Ring LLC, “Ring video doorbell,” 2024. [Online]. Available: https://ring.com/
[2] Google Store, “Google nest doorbell,” 2024. [Online]. Available: https: //store.google.com/product/nest_doorbell
[3] Itseez, “Open source computer vision library,” 2015. [Online]. Available: https://opencv.org
[4] P. Viola and M. Jones, “Rapid object detection using a boosted cascade of simple features,” CVPR, 2001.
[5] K. Zuiderveld, “Contrast limited adaptive histogram equalization,” Graphics Gems IV, 1994.
[6] T. Ojala, M. Pietikainen, and T. Maenpaa, “Multiresolution gray-scale and rotation invariant texture classification with local binary patterns,” IEEE PAMI, vol. 24, no. 7, pp. 971–987, 2002.
[7] T. Ahonen, A. Hadid, and M. Pietikainen, “Face description with local binary patterns: Application to face recognition,” IEEE PAMI, vol. 28, no. 12, pp. 2037–2041, 2006.
[8] X. Tan and B. Triggs, “Enhanced local texture feature sets for face recognition under difficult lighting conditions,” IEEE Trans. Image Processing, vol. 19, no. 6, pp. 1635–1650, 2010.
[9] W. R. Stevens and S. A. Rago, Advanced Programming in the UNIX Environment, 3rd ed. Addison-Wesley, 2013.
[10] M. Kerrisk, The Linux Programming Interface. No Starch Press, 2010.
[11] T. Karras, S. Laine, and T. Aila, “A style-based generator architecture for generative adversarial networks,” CVPR, 2019.

ANEXO I – ACESSO AO REPOSITÓRIO DO PROJETO
O código-fonte integral (todo em C/C++), os scripts auxiliares, o histórico de versões e a documentação estão hospedados em ambiente Git público, na branch main.
O repositório contém:
- core.cpp: núcleo de controle com recursos de tempo real;
- visao.cpp: pipeline de visão (liveness + reconhecimento);
- visao_core.hpp: algoritmos compartilhados (Tan-Triggs, LBPH, χ

2
, FFT);
- treinar.cpp: treino do classificador (captura multi-ângulo em 7 fases e treino por datasets);
- extrair_rostos.cpp: extração de rostos para a classe negativa;
- baixar_rostos.sh, | baixar_diversidade.py,
atualizar_negativos.sh: | scripts | de | montagem | e
balanceamento da classe negativa;
- Makefile, haarcascade_frontalface_default.xml e docs/ (relatório, diagramas e projeto Fritzing).
Observação: o modelo modelo_lbph.txt e as pastas dataset_*/ e fotos_*/ contêm dados biométricos, são gerados localmente e não são versionados (ver .gitignore). As credenciais do bot do Telegram também não são versionadas.

Link de Acesso: https://github.com/FuyteaorUnB/SOE-2026. 1

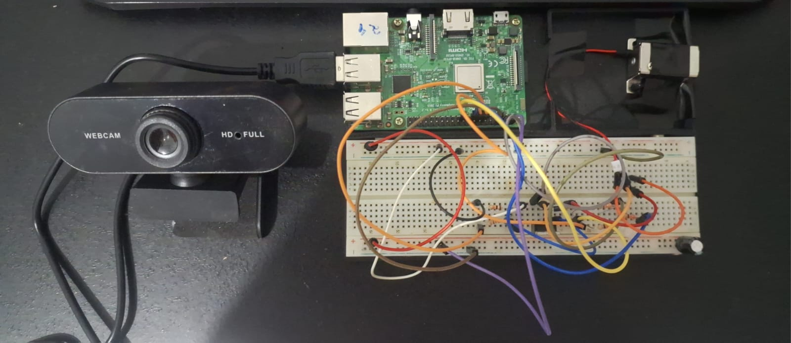
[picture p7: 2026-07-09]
docs/foto_prototipo.png

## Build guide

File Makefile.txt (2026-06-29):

# Makefile - Sistema de Controle de Acesso
CXX       := g++
COREFLAGS := -O2 -pthread
CVFLAGS   := -O2 -std=c++17 $(shell pkg-config --cflags opencv4)
CVLIBS    := $(shell pkg-config --libs opencv4)

all: sistema_core visao treinar

sistema_core: core.cpp
	$(CXX) $(COREFLAGS) core.cpp -o sistema_core

visao: visao.cpp visao_core.hpp
	$(CXX) $(CVFLAGS) visao.cpp -o visao $(CVLIBS)

treinar: treinar.cpp visao_core.hpp
	$(CXX) $(CVFLAGS) treinar.cpp -o treinar $(CVLIBS)

core: sistema_core
clean:
	rm -f sistema_core visao treinar

.PHONY: all clean core

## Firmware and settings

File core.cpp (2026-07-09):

// Controle de baixo nível da fechadura e LEDs

#include <iostream>
#include <string>
#include <thread>
#include <mutex>
#include <atomic>
#include <chrono>
#include <cstdlib>
#include <cstring>
#include <cerrno>
#include <fcntl.h>
#include <unistd.h>
#include <poll.h>
#include <signal.h>
#include <time.h>
#include <sys/stat.h>
#include <sys/types.h>
#include <sys/mman.h>
#include <sched.h>
#include <pthread.h>

#define PIPE_PATH "/tmp/gate_pipe"

#define PIN_TRANCA "17"
#define PIN_LED_R  "22"
#define PIN_LED_G  "27"
#define PIN_LED_B  "10"

#define PRIO_MONITOR 50
#define CPU_MONITOR   3
#define CPU_LED       2

std::atomic<bool> rodando{true};
bool portaAberta   = false;
bool alertaIntruso = false;

std::mutex mtx;
std::mutex hwMtx;

int cacheR = -1, cacheG = -1, cacheB = -1, cacheT = -1;

void escreverGPIO(const std::string& pin, int valor) {
    std::lock_guard<std::mutex> lock(hwMtx);

    if (pin == PIN_LED_R && valor == cacheR) return;
    if (pin == PIN_LED_G && valor == cacheG) return;
    if (pin == PIN_LED_B && valor == cacheB) return;
    if (pin == PIN_TRANCA && valor == cacheT) return;

    if (pin == PIN_LED_R) cacheR = valor;
    if (pin == PIN_LED_G) cacheG = valor;
    if (pin == PIN_LED_B) cacheB = valor;
    if (pin == PIN_TRANCA) cacheT = valor;

    std::string estado  = (valor == 1) ? "dh" : "dl";
    std::string comando = "sudo pinctrl set " + pin + " op " + estado + " > /dev/null 2>&1";
    (void)std::system(comando.c_str());
}

void tratarSinal(int) { rodando = false; }

void inicializarHardware() {
    std::cout << "[HW] Inicializando componentes..." << std::endl;
    escreverGPIO(PIN_TRANCA, 0);
    escreverGPIO(PIN_LED_R, 1);
    escreverGPIO(PIN_LED_G, 0);
    escreverGPIO(PIN_LED_B, 0);
}

bool configurarTempoReal(int prioridade, int cpu, const char* nome) {
    cpu_set_t set;
    CPU_ZERO(&set);
    CPU_SET(cpu, &set);
    if (pthread_setaffinity_np(pthread_self(), sizeof(set), &set) != 0)
        std::cerr << "[RT] (" << nome << ") Falha ao definir afinidade CPU " << cpu << std::endl;

    struct sched_param sp;
    std::memset(&sp, 0, sizeof(sp));
    sp.sched_priority = prioridade;
    if (pthread_setschedparam(pthread_self(), SCHED_FIFO, &sp) != 0) {
        std::cerr << "[RT] (" << nome << ") SCHED_FIFO falhou. Operando em modo normal." << std::endl;
        return false;
    }
    return true;
}

void threadMonitorPipe() {
    configurarTempoReal(PRIO_MONITOR, CPU_MONITOR, "monitor_pipe");

    int fd = -1;
    while (rodando) {
        fd = open(PIPE_PATH, O_RDONLY | O_NONBLOCK);
        if (fd >= 0) break;
        std::this_thread::sleep_for(std::chrono::milliseconds(200));
    }
    if (!rodando) return;

    std::cout << "[IPC] Pipe aberto. Aguardando sinais..." << std::endl;

    while (rodando) {
        struct pollfd pfd;
        pfd.fd = fd; pfd.events = POLLIN; pfd.revents = 0;

        int ret = poll(&pfd, 1, 100);
        if (ret < 0) {
            if (errno == EINTR) continue;
            std::cerr << "[IPC] Erro no poll: " << errno << std::endl;
            break;
        }
        if (ret == 0) continue;

        if (pfd.revents & POLLIN) {
            char comando;
            ssize_t n = read(fd, &comando, 1);
            if (n == 1) {
                if (comando == 'F') {
                    { std::lock_guard<std::mutex> lk(mtx); portaAberta = true; }
                    std::cout << "[CORE] Acesso autorizado. Abrindo trava." << std::endl;
                    escreverGPIO(PIN_TRANCA, 1);
                    std::this_thread::sleep_for(std::chrono::seconds(4));
                    escreverGPIO(PIN_TRANCA, 0);
                    { std::lock_guard<std::mutex> lk(mtx); portaAberta = false; }
                }
                else if (comando == 'I') {
                    { std::lock_guard<std::mutex> lk(mtx); alertaIntruso = true; }
                    std::cout << "[CORE] Alerta: Intruso detectado!" << std::endl;
                    std::this_thread::sleep_for(std::chrono::seconds(6));
                    { std::lock_guard<std::mutex> lk(mtx); alertaIntruso = false; }
                }
            }
        }
    }
    if (fd >= 0) close(fd);
}

void threadControleLED() {
    configurarTempoReal(PRIO_MONITOR - 10, CPU_LED, "led_periodico");

    const long PERIODO_NS = 100L * 1000L * 1000L;
    struct timespec proximo;
    clock_gettime(CLOCK_MONOTONIC, &proximo);

    bool estadoPisca = false;
    int  contador    = 0;

    while (rodando) {
        bool statusPorta, statusAlerta;
        { std::lock_guard<std::mutex> lk(mtx);
          statusPorta  = portaAberta;
          statusAlerta = alertaIntruso; }

        if (statusPorta) {
            escreverGPIO(PIN_LED_R, 0); escreverGPIO(PIN_LED_G, 1); escreverGPIO(PIN_LED_B, 0);
        }
        else if (statusAlerta) {
            if (++contador >= 2) {
                estadoPisca = !estadoPisca;
                contador = 0;
                if (estadoPisca) { escreverGPIO(PIN_LED_R,1); escreverGPIO(PIN_LED_G,0); escreverGPIO(PIN_LED_B,0); }
                else             { escreverGPIO(PIN_LED_R,0); escreverGPIO(PIN_LED_G,0); escreverGPIO(PIN_LED_B,1); }
            }
        }
        else {
            escreverGPIO(PIN_LED_R, 1); escreverGPIO(PIN_LED_G, 0); escreverGPIO(PIN_LED_B, 0);
            contador = 0; estadoPisca = false;
        }

        proximo.tv_nsec += PERIODO_NS;
        while (proximo.tv_nsec >= 1000000000L) { proximo.tv_nsec -= 1000000000L; proximo.tv_sec++; }
        clock_nanosleep(CLOCK_MONOTONIC, TIMER_ABSTIME, &proximo, nullptr);
    }
}

int main() {
    signal(SIGINT,  tratarSinal);
    signal(SIGTERM, tratarSinal);

    std::cout << "Iniciando Sistema de Controle de Acesso..." << std::endl;

    if (mlockall(MCL_CURRENT | MCL_FUTURE) == 0)
        std::cout << "[RT] mlockall(): Memoria em RAM travada com sucesso." << std::endl;
    else
        std::cerr << "[RT] Falha no mlockall(). (Requer sudo)" << std::endl;

    unlink(PIPE_PATH);
    mkfifo(PIPE_PATH, 0666);
    chmod(PIPE_PATH, 0666);

    inicializarHardware();

    std::thread tMonitor(threadMonitorPipe);
    std::thread tLED(threadControleLED);

    tMonitor.join();
    tLED.join();

    std::cout << "\n[CORE] Desligando sistema..." << std::endl;
    cacheR = cacheG = cacheB = cacheT = -1;
    escreverGPIO(PIN_TRANCA, 0);
    escreverGPIO(PIN_LED_R, 0);
    escreverGPIO(PIN_LED_G, 0);
    escreverGPIO(PIN_LED_B, 0);
    unlink(PIPE_PATH);
    munlockall();
    
    return 0;
}

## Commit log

2026-05-09 Código em Python (PC2)
    Apenas faz funcionar o sistema de detecção de rosto ou foto.
2026-05-09 Firmware em Python
    Apenas faz funciona o sistema de detecção de rosto ou foto, além do destravamento da fechadura.
2026-05-09 Haarcascade
    Detecção de rostos
2026-06-29 Remoção de informações sensíveis
2026-07-07 "Esquemático" no fritzing
    [SOE - v1.fzz]
2026-07-07 Reformulação do READ.ME para melhor compreensão
2026-07-07 Adição dos arquivos à pasta docs
    [SOE - v1.fzz]
2026-07-07 Rename Diagrama de Blocos PC4.png to diagrama_blocos.png
2026-07-09 Entrega Final - Remoção de Informações Sensíveis
